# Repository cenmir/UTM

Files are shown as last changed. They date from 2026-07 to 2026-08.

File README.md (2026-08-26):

# Universal Testing Machine

Based on the work done by [Stefan from CNC kitchen](https://www.youtube.com/watch?v=uvn-J8CbtzM) and the students [Stephen Jose Mathew and Vijay Francis](https://hj.diva-portal.org/smash/get/diva2:1472019/FULLTEXT01.pdf) this is the continuation of that work. The machine is used at the Jönköping University - School of Engineering for teaching various mechanical engineering courses and the design, verification and validation of tensile testing equipment is in focus.

## Firmware

The firmware is is based on the HX711 amplifier, uses 10Hz polling rate and the TMC2160 driver on two MKS TMC2160_57 board, each driving a AMP57TH76-4280 Nema 23 stepper motor. The motors are geared down 20 times using EPL64/2 planetary gears. 

Rob Tillarts HX711 library is used to read raw values at 10Hz non-blocking (when data is available).

For drving the motors, one controll signal is sent to both drivers using the MobaTools library.

Additionally on each motor shaft end a magnet is attached and its rotational position contactlessly measured by a AS5600 magnetic encoder using Rob Tillats library. This is used to measure the rotational speed of the motors as well as getting the total amount of rotation.

## Software

The software is written in python using the PyQt6 framework for the GUI.

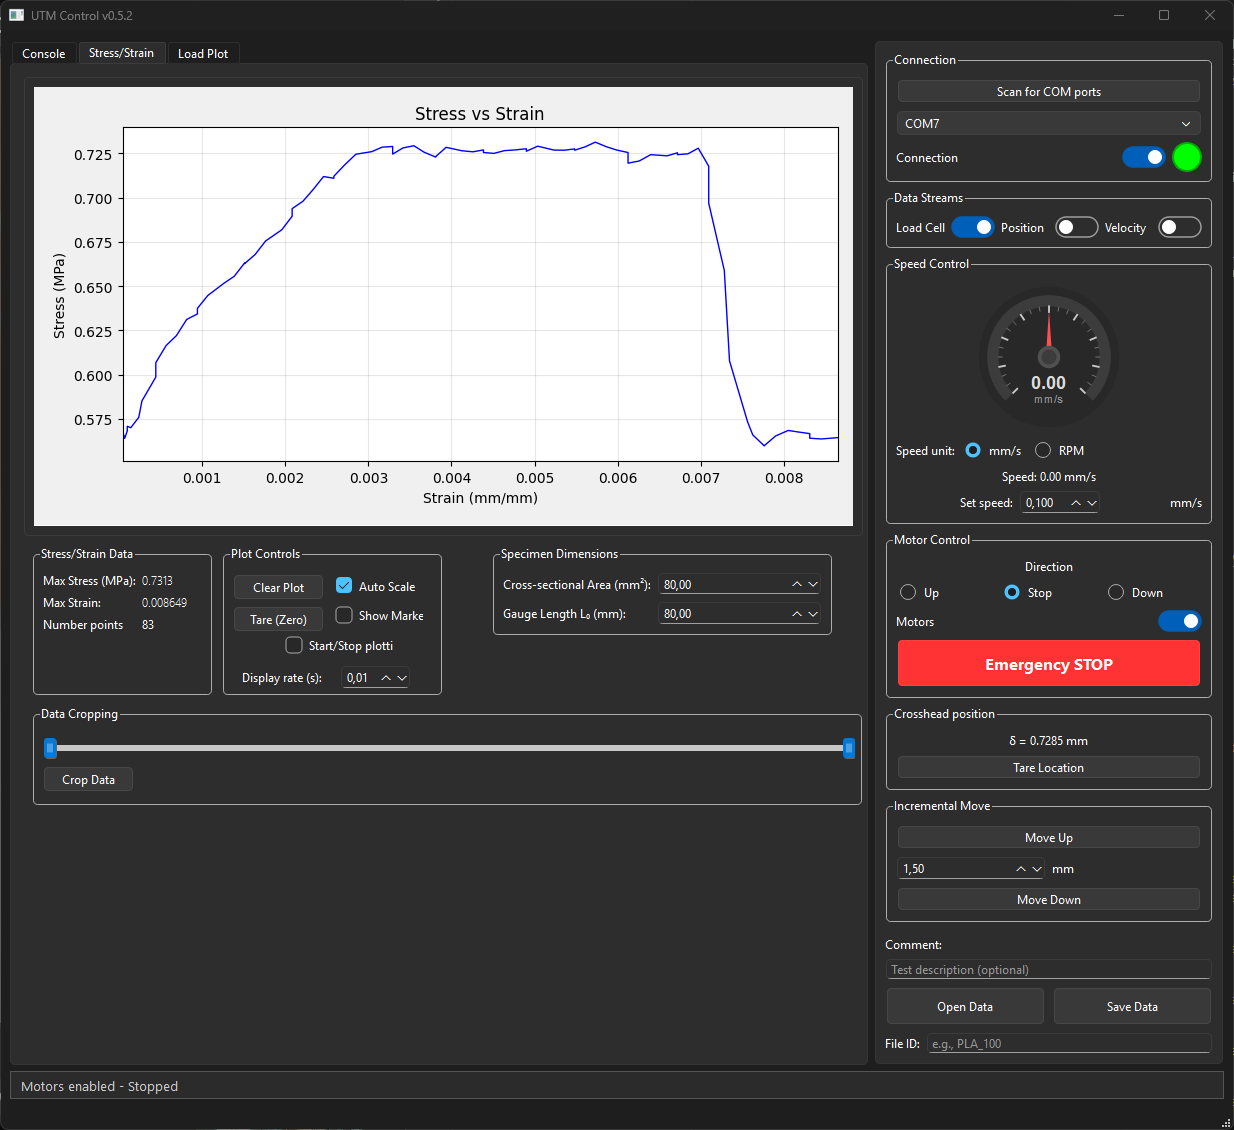
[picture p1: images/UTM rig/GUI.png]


## Hardware

### Mechanics BOM

| Qty | Component | Description |
|-----|---|---|
| 1 | [Aluminium Profile 80x80](https://www.alucon.se/product/aluminiumprofil-80x80-basic-t-spar-8-1-mm) | Frame extrusions |
| 2 | EPL-Q64 i20 | Planetary gearboxes (20:1 reduction) |
| 2 | Tr 22x5 TH22 | Trapezoidal lead screws (5mm pitch) |
| 4 | SKF-6005-2Z | Deep groove ball bearings |

### Electronics BOM

| Qty | Component | Description |
|-----|---|---|
| 2 | Nema 23 AMP57TH76-4280 | Stepper motors (1.85 Nm stall torque) |
| 2 | MKS TMC2160_57 | Stepper driver boards |
| 1 | ESP32 Lolin D32 | Microcontroller |
| 1 | HX711 | Load cell amplifier |
| 1 | Anyload 101BH-3t | Load cell (3 ton capacity) |
| 2 | AS5600 | Magnetic rotary encoders |

### Camera System (for DIC)

| Qty | Component | Specification |
|-----|---|---|
| 1 | Basler acA2440-35um | USB 3.0 camera |
| 1 | Azure-2514M | 25mm lens, 5MP, 2/3" sensor |
| - | LED lights | Specimen illumination |

## Digital Image Correlation

Two spray-painted markers on the specimen gauge are tracked in every camera frame. Their pixel
separation `L_px` against the frozen reference `Px₀` gives engineering strain directly on the
specimen, so the measurement carries no machine compliance and no grip slip.

### Hardware

Basler acA2440-35um over USB 3.0, 25 mm lens, LED illumination. The camera is mounted with the
specimen across the sensor, so every frame is rotated 90° before detection — the loading axis is
the *rotated* frame's Y.

### Software

`camera_manager.py` thresholds each frame, finds the two markers, and emits strain.
`utm_analysis.py` turns a saved CSV into E, σ_y, UTS, ε_f, toughness and the anchor. That module and
its siblings are deliberately **stdlib-only**, so results can be recomputed on any machine with no
camera stack installed.

---

# Getting started

```bash
git clone https://github.com/AdithyaSivakumar-3/UTM.git
cd UTM
python -m venv .venv && .venv\Scripts\activate      # Windows
pip install -r requirements.txt
python "Software/UTM_PyQt6/main.py"
```

Developed on **Python 3.14** and Windows. `requirements.txt` is grouped by what you want to do —
read the comments before installing everything.

**You do not need the rig to work on this.** `pypylon` is the only hardware-specific dependency;
skip it and every offline path still runs. Without a camera the app starts but cannot track.

## Where to look first

| File | What it is |
|---|---|
| `Software/UTM_PyQt6/docs/ROADMAP.md` | **Start here.** Living status of every feature: done, planned, blocked, and what needs rig time. |
| `Software/UTM_PyQt6/main.py` | The application. Control loop, live plots, CSV export, all UI. |
| `Software/UTM_PyQt6/camera_manager.py` | Camera, thresholding, marker detection, strain. |
| `Software/UTM_PyQt6/utm_analysis.py` | The canonical analyser. Every script and the app share it — do not re-implement it. |
| `Software/UTM_PyQt6/registry.json` | The specimen register: every test, with its computed properties. |
| `Software/UTM_PyQt6/dic_replay.py` | Replays a saved capture through the real detector and explains why tracking failed. |
| `documentation/` | Slide-deck and poster generators. Each rebuilds from data, never from typed-in numbers. |

## What is NOT in this repository

**The measured data itself.** `Software/UTM_PyQt6/Test data/` holds every test, in two folders
(`8.6.20 - Tensile test to Failure/` and `Smart Features - Advanced Test Modes/`). The folder
*structure* is committed, along with each run's `run.json`, generated report and photographs — but
the bulk is not:

| excluded | pattern | why |
|---|---|---|
| test CSVs | `*.csv` | the measurements themselves |
| capture stills | `**/frames*/`, `*.tif` | one specimen's stills run to 1.7 GB |
| capture video | `*.avi`, `*.mkv` | lossless by design |
| generated reports | `Software/UTM_PyQt6/reports/` | reproducible from the CSV |
| MOT session pack | `Validation docs/` | multi-GB videos |

The tree is ~54 GB in full. `registry.json` references the CSV paths, so analysis and deck scripts
will not find their inputs on a fresh clone — ask for the data folder separately if you need to
reproduce a result rather than write new code.

## Conventions worth knowing before you change anything

- **Engineering stress and strain** throughout. Force ÷ *original* area; ΔL/L₀. The CSV also carries
  a true-strain column, kept only so old files still parse.
- **Px₀ is frozen AFTER the preload**, so the strain axis starts at a seated specimen. It has
  exactly one owner — the Calibrate Px₀ button. Nothing else may move it.
- **Elastic modulus is the steepest straight run**, chosen per specimen, not a fixed strain window.
  `analyze()` also returns `E_fixed` so older numbers remain reproducible.
- **Fracture is detected on load collapse.** A DIC jump alone is not enough — it misfires on
  ductile material and on a lost marker.
- Force is tared at the preload, so an unloaded or fractured specimen reads *negative*.

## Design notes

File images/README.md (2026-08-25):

# images/

Figures used by the slide decks and the analysis scripts. These were loose in the repository root
until 2026-08-25; the names always said which test series they belonged to, so the folders just
make that visible.

| folder | what is in it |
|---|---|
| `V4/` | 8.6.19 / 8.6.3 staircase and linearity series |
| `V5/` | 8.6.20 V5 tensile-to-failure, and the V5a/b/c comparison set |
| `V6/` | V6 quintet — ductility, fracture patterns, offset factor, repeatability |
| `V6a/` | V6a 100 % infill series, including the V6a-vs-V5 overlays |
| `features/` | `feat_*` — proof figures for app features (auto-stop, strain rate, DIC halt …) |
| `rig/` | hardware and UI: enclosure CAD, DIC HUD and Settings screenshots, preload schedule |

Not to be confused with:

- **`graphics/`** — rig documentation referenced from `README.md` and `PROJECT_REQUIREMENTS.md`
  (GUI, schematic, dimensions). Different audience, so it stays where the docs point at it.
- **`documentation/*.png`** — figures generated by the deck builders that live beside them, and
  are rewritten on every build.

## If you move one of these

The scripts `chdir` to the repository root, so every reference is a path from the root such as
`"images/V6a/V6a_stress_strain.png"`. Grep for the filename before moving it — and note that
`pic_or_ph()` in the deck builders substitutes a PLACEHOLDER BOX for a missing image rather than
failing, so a broken path produces a deck that builds cleanly and is quietly wrong. After any
move, rebuild and check the picture count is unchanged:

```
python documentation/scripts/generate_v6a_slides.py
python -c "from pptx import Presentation; p=Presentation('documentation/decks/V6a_8_6_20_slides.pptx'); \
print(sum(1 for s in p.slides for sh in s.shapes if sh.shape_type==13), 'pictures')"
```

At the time of the move that was **90 pictures across 125 slides**.

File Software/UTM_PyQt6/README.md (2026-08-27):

# Software/UTM_PyQt6/

The UTM DIC application. `python main.py` from **this** directory starts it.

## Why the modules are flat

The 15 `.py` files beside `main.py` are the application. They import each other by bare module
name — `from camera_manager import CameraManager` — so they have to sit together on the path.
That is why they were left loose when everything else was filed away in 2026-08-25: putting them
in a subfolder would mean turning the app into a package and rewriting every import, which is a
different job with a different risk.

| module | role |
|---|---|
| `main.py` | the window, the control loop, the CSV writer |
| `camera_manager.py` | Basler capture, blob detection, DIC strain |
| `serial_manager.py` | the link to the rig firmware |
| `control_policies.py` | closed-loop test modes (strain rate, cyclic, staircase, …) |
| `utm_analysis.py` | the shared analyser: E, σ_y, UTS, ε_f, force anchor, fracture detection |
| `utm_registry.py` · `utm_report.py` | the test registry and the one-click per-test report |
| `utm_recipes.py` | saved settings profiles (`recipes/`) — Default, TPU |
| `utm_capture.py` · `utm_capdlg.py` | frame/video capture and its setup dialog |
| `utm_camdlg.py` · `utm_autocal.py` | DIC camera setup and auto-calibration |
| `utm_dic.py` · `utm_wizard.py` | DIC health readout and the guided wizard |
| `utm_postproc.py` · `utm_postdlg.py` | DIC post-processing: strain from a RECORDED video, and its tab |
| `theme.py` · `widgets.py` | look and custom controls |

## Folders

| folder | what |
|---|---|
| `tools/` | diagnostic and build scripts — ROI picker, blob checker, DIC replay, exe build |
| `tests script/` | camera and phase-8.6 test scripts |
| `docs/` | ROADMAP, TESTING_TODO, TEST_FAILURES, RECALIBRATE_ROI, COMMANDS |
| `ui/` | the Qt Designer `.ui` file, and `ui/help/` — the mode-help images |
| `recipes/` | saved settings profiles, seeded on first launch (Default, TPU) |
| `output/` | everything the app and its tools WRITE: `captures/`, `diagnostics/`, `setup_output/`, `full_frame_output/`, `test_images/`. Gitignored in one line |
| `Test data/` | every test CSV and its per-specimen folder — see below |

`CAPTURE_ROOT`, the `.ui` path, `ui/help` and `RECIPES_DIR` are all built from `__file__`, so they
follow the module — but they do NOT follow a folder that moves underneath them. A wrong one does
not raise; it points at a directory that is not there, and the symptom is a capture that never
appears or a help image that is blank. If you move any of these, check
`main.py` (`UI_FILE`, `CAPTURE_ROOT`, the `ui/help` lookup) and `utm_recipes.RECIPES_DIR`.

## Running anything in `tools/` or `tests script/`

From **this** directory, not from inside the subfolder:

```
cd Software/UTM_PyQt6
python tools/dic_replay.py
```

Their data and output paths are relative to this directory, and the ones that import app modules
carry a two-line header putting the parent on `sys.path`.

## DIC post-processing (the fourth tab)

Measures strain from a **recorded video** — ours, or a specimen filmed on the MOT XT-205 video
extensometer — so the two instruments can be compared on the same footing.

Load a video, place two tracking boxes on the speckle (or press Auto-detect for sprayed dots),
press Run. The strain-vs-time plot builds on the right as it goes.

**The strain maths is not re-implemented.** `utm_postproc` calls `utm_dic.dic_strain()`, and so
does the live camera path in `camera_manager.calculate_dic_strain()`. Strain is a pixel ratio —
`(L − L₀)/L₀` — with no gauge, calibration or unit in it, so a pull and the same pull replayed
from its recording must not be able to disagree.

Two things it gets right that are easy to get wrong:

- **Tracking is against the REFERENCE patch, not the previous frame.** Frame-to-frame tracking
  accumulates drift, and over 1682 frames a fraction of a pixel per frame exceeds the strain being
  measured. When correlation falls below the floor it re-seeds and FLAGS that frame rather than
  silently accumulating error.
- **Frame rate is measured, not believed.** Every video this rig has produced declares 35 fps in
  its container; S26 and S35 actually ran at 19.93 and S37 at 33.55. On load the tab reads the
  true rate from the capture folder's `frames/index.csv` (or `run.json`) and says where it got it.
  Videos from another camera have no sidecar, and the tab says so instead of assuming.

**Comparing several videos.** Add any number; each keeps its own extensometer, frame rate, box
size and tracking method, because two videos never have their markers in the same place and an
extensometer recording shares neither the frame rate nor the scale of ours. `Run all pending`
measures them one after another and every completed run stays on the plot with its own colour and
legend label. That is how an extensometer recording is put beside one of ours on the same axes,
measured with the same pixel-to-strain rule.

**Tracking method** is selectable, and the choice matters when comparing:

| mode | what it does | when |
|---|---|---|
| intensity-weighted centroid | contour selects the marker, intensity weights the centre | default — most precise |
| binary centroid | exactly what `camera_manager` does | comparing against a live run: removes the estimator as a variable |
| correlation | matches the pattern, no marker needed | speckle; chosen automatically when no marker is found |

Measured on S25/S26 over a matched strain window: intensity-weighted 15–17 µε, binary ~25 µε,
live rig 28 µε. Note the box size dominates all of it — a 24 px half-box on a 60 px dot gives
313 µε, because it sees only flat interior. Auto-detect and snapping now size the box to the marker.

Validated against S26: post-processing its `video.avi` reproduces that run's own live DIC to
**273 µε RMS over a 5.6 % strain range** (~0.5 % of reading), with L₀ agreeing to 0.005 %.

## Test data

Everything lives under **`Test data/`**, in two folders:

| folder | what | registry rows |
|---|---|---|
| `Test data/8.6.20 - Tensile test to Failure/` | the tensile-to-fracture campaign — one folder per specimen (`Specimen_S<n>_…`), each holding the CSV, its generated report/plots, and the frame-capture folder if the run recorded one | 27 |
| `Test data/Smart Features - Advanced Test Modes/` | the closed-loop protocol runs (cyclic, staircase, relaxation, creep) plus the older `8.6.3/` set | 7 |

They were gathered under one parent in the 2026-08 reorganisation; before that they sat loose in
this directory. **`registry.json` records every test by path**, and the deck builders in
`documentation/` read those same paths, so a move here invalidates both. Both were repointed at
the time, and the check is one line:

Run it **from the repository root**, not from this directory — the paths in `registry.json` are
stored relative to the root, so from here every one of them looks missing:

```
python -c "import json,os; r=json.load(open('Software/UTM_PyQt6/registry.json')); print(sum(1 for x in r if not os.path.isfile(x['csv'])),'unresolved of',len(r))"
```

That must print `0 unresolved`. If it does not, repoint by searching for each CSV's **basename**
rather than assuming where the folder went — specimen folders get renamed too (S37's gained a
`_Video15` suffix after its run, which broke its row and a hard-coded path in the deck scripts).

**The CSVs themselves are gitignored** (`*.csv`), as are the capture folders (`**/frames*/`,
`*.avi`, `*.mkv`, `*.tif`) — one specimen's stills run to 1.7 GB, and the tree as a whole is 54 GB.
What IS committed per specimen is the small stuff: `run.json`, the generated report PDF/PNGs, and
photographs. So the folder structure is in git while the bulk data stays local.

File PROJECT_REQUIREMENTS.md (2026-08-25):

# Project Requirements

This document outlines the hardware and software requirements for the Python-based Universal Testing Machine (UTM) application.

## Hardware

*   **Universal Testing Machine (UTM):** The existing custom-built machine with:
    *   2x Nema 23 stepper motors (AMP57TH76-4280) (1.85 Nm stall torque)
    *   2x MKS TMC2160 Nema23 driver board2
    *   1x HX711 load cell amplifier
    *   1x Anyload 101BH-3t load cell (3 ton capacity)
    *   2x AS5600 magnetic encoders
    *   1x ESP32 LolinD32 Board
    *   [Aluminium extrusions](https://www.alucon.se/product/aluminiumprofil-80x80-basic-t-spar-8-1-mm)
    *   2x EPL-Q64 i20
    *   2x Tr 22x5  TH22 Trapezoidal lead screws
    *   4x SKF-6005-2z Deep groove ball bearings
*   **Camera:**
    *   **Model:** Basler acA2440-35um
    *   **Interface:** USB 3.0
*   **Lens:**
    *   **Model:** Azure-2514M
    *   **Focal Length:** 25mm
    *   **Max Resolution:** 5MP
    *   **Sensor Format:** 2/3"
*   **Lighting:** LED lights for illuminating the test specimen.

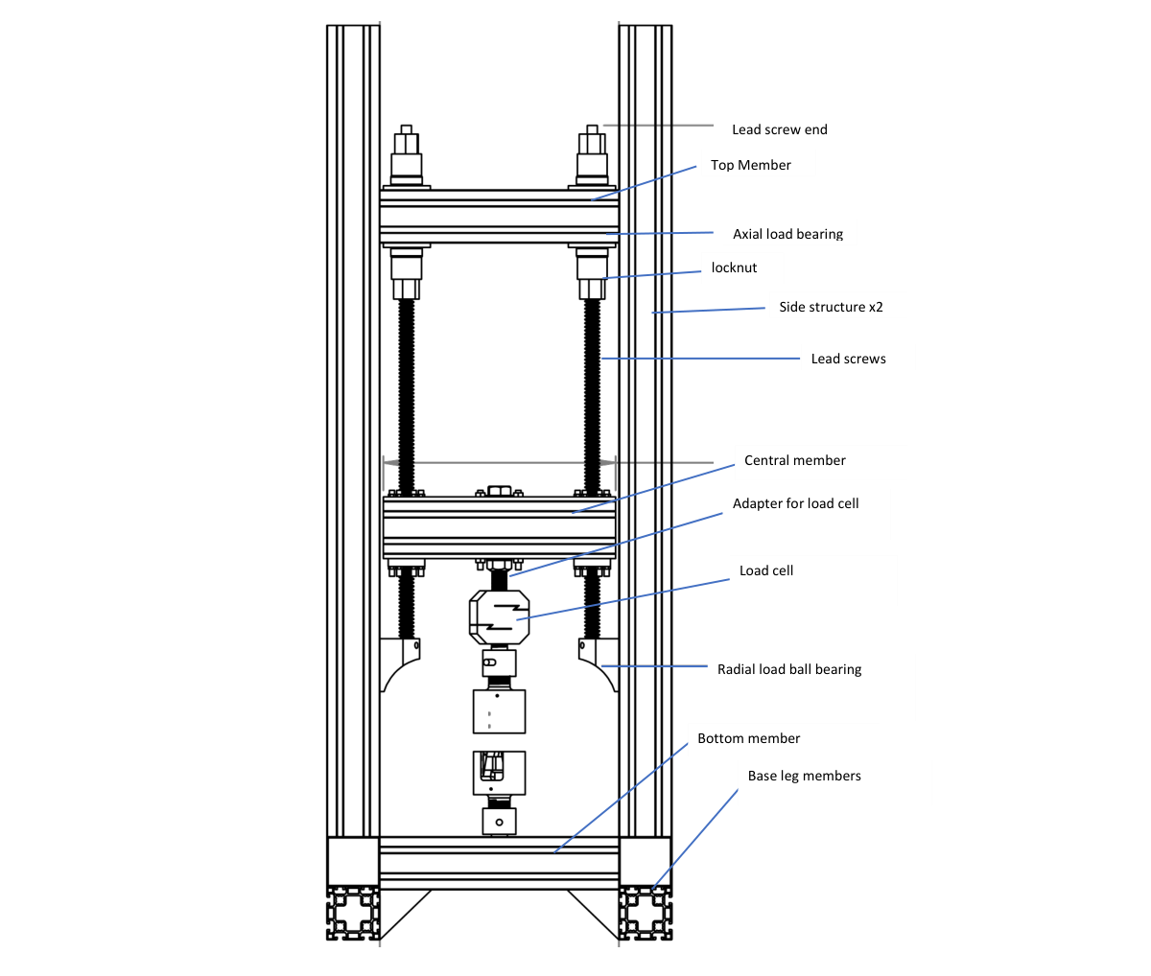
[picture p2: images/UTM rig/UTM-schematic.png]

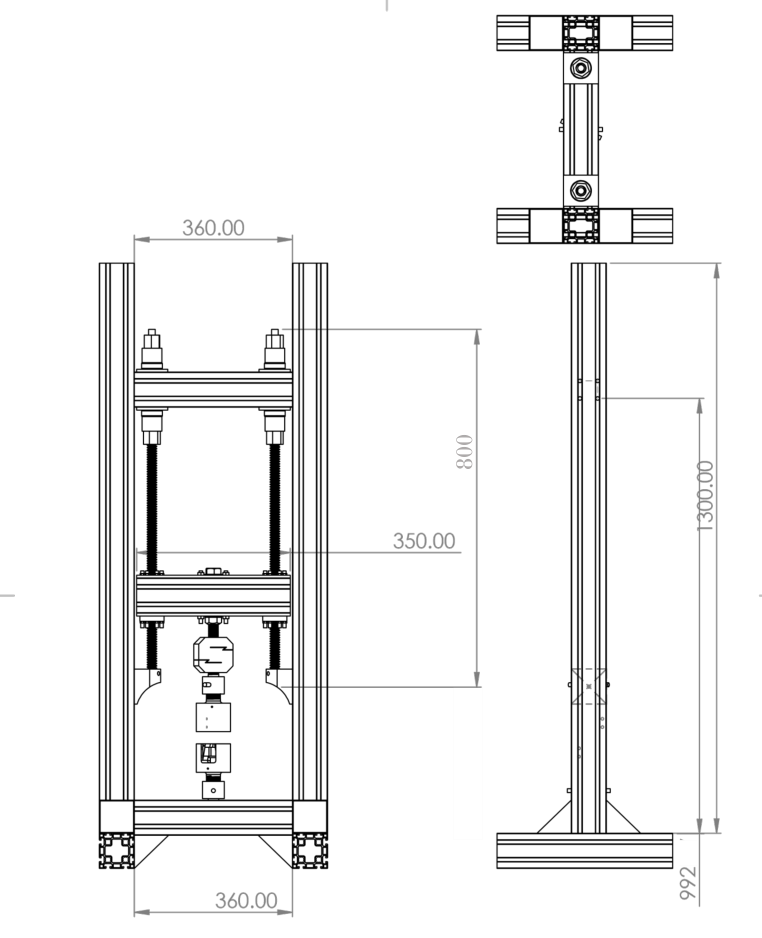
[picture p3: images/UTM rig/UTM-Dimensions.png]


## Software

### Core Libraries

*   **GUI Framework:** PyQt6
*   **Serial Communication:** `pyserial` for communicating with the Arduino microcontroller.
*   **Camera Integration:** A Python wrapper for the Basler Pylon SDK will be needed. The `pypylon` library is the standard for this.
*   **Numerical Computing:** `numpy` for handling numerical data and calculations.
*   **Plotting:** `pyqtgraph` or `matplotlib` for real-time data plotting within the PyQt6 application. `pyqtgraph` is generally recommended for high-performance real-time plotting in PyQt.
*   **Data Storage:** `pandas` and `h5py` (for HDF5) or a similar library for saving data.

### Digital Image Correlation (DIC)

*   **1D Two-Point Tracking:** The primary goal for DIC is to track two points on the specimen to measure strain.
*   **Image Processing:** `OpenCV-Python` (`opencv-python`) will be used for image manipulation, feature detection, and tracking.
*   **Algorithm:**
    1.  The user will select two points of interest (e.g., by clicking on the camera feed).
    2.  A feature detection algorithm (e.g., Shi-Tomasi corner detection or a simple blob detector) will be used to identify features within a small region of interest (ROI) around the selected points.
    3.  An optical flow algorithm (e.g., Lucas-Kanade) will be used to track these features from frame to frame.
    4.  The distance between the tracked points will be calculated in each frame to determine the elongation and, subsequently, the strain.

## Installation of Dependencies

The following commands will be needed to install the required Python packages:

```bash
pip install PyQt6
pip install pyserial
pip install numpy
pip install pyqtgraph
pip install pandas
pip install h5py
pip install opencv-python
pip install pypylon
```

**Note on `pypylon`:** The `pypylon` library requires the Basler Pylon SDK to be installed on the system. The user has indicated that the Basler Pylon 25.11.0 drivers are already installed.

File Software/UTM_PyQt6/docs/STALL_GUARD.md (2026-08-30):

# The velocity stall guard

**Status: ENABLED by default since 2026-08-30.** Operator switch in
**Motor Control ▸ Stall guard (velocity)**.

> **2026-08-30 — turned back on for the student campaign, by the project owner's decision.**
> It was switched off on 2026-08-28 for the reasons set out below, which still stand: this
> guard fires on healthy motion, and the fault it was written for was fixed mechanically.
> The judgement that reversed it is about who is at the rig. With ~40 groups running pulls
> largely unattended over seven weeks, a guard that occasionally stops a good move is the
> cheaper failure than one that is absent when a genuine bind happens.
>
> If it cries wolf during the campaign, reach for the **grace period** (`_start_movement_grace_period`,
> which covers the acceleration ramp) before reaching for the default. A student who is told
> to untick a safety box will leave it unticked.

This is the guard that prints:

```
⚠ WARNING: MOTOR STALL DETECTED!
⚠ Motors stopped for safety!
Motors DISABLED (stopped)
```

It is **not** the 0.05 mm / 6 s position guard described in `ROADMAP.md`. There are two
independent stall detectors and only this one is switchable.

| | velocity guard (this file) | position guard |
|---|---|---|
| where | `main.py` `_handle_motor_stall`, in the velocity handler | `_policy_step` / auto-stop path |
| test | motor RPM below a fixed floor | crosshead advance over a time window |
| scales with commanded speed | **no** | yes (`_stall_threshold_mm`) |
| switchable | **yes, default ON** | no |

---

## What it does

Fires when **all** of these hold:

1. `stall_detection_enabled` — **on** unless the operator unticks the box
2. Motors enabled
3. Direction is not Stop
4. Past the 1-second movement-start grace period
5. Not in a preload
6. **Both** instantaneous and averaged RPM below **0.5**, for **3 consecutive** readings

Then it sends `EStop`, disables the motors and resets direction to Stop.

---

## Why it was written, and why that reason is gone

| Date | Event |
|---|---|
| **2026-06-22** | `a4573d8` adds the guard. The rig is stalling near 2.6 kN. |
| 2026-07-28 | S15 stalls at 2.6 kN. **S16 fractures at 3792 N the same day**, +46 % on the same rig at the same speed. |
| **2026-08-12** | `9061daf` — the root cause is found. |

The "torque ceiling" was never a motor limit. **The load holders had worked loose, the
crossheads sat out of alignment, and the motor was spending its torque on binding instead of
on the specimen.** Re-tightened and lubricated, the rig pulls 3.5 kN with no stutter. The
commit puts it plainly: *"A fastener, not a purchase and not a code change."*

Eleven 100 %-infill specimens had already fractured at 3586–3826 N across three months —
straight through the supposed ceiling. The evidence was on disk before the fault was found.

**A mechanical fault was met with a software guard.** The guard did real work at the time:
S15 and T7 were caught by it and excluded from the results rather than silently averaged in.
But the fault it was compensating for has been repaired, and the guard outlived it.

---

## Why it misfires now

Two design faults, both visible in an ordinary jog:

**The averaged term lags the ramp at both ends.** From a real run:

```
<< Going up fast!
Velocity:   2.76 RPM (avg:   0.14 RPM)     <- avg still ~0 while the motor is turning
Velocity:   3.84 RPM (avg:   0.72 RPM)
...
Velocity: 453.99 RPM (avg: 451.83 RPM)
<< Stop and halt!
Velocity:   3.22 RPM (avg:  18.14 RPM)
Velocity:   0.00 RPM (avg:   9.53 RPM)     <- instantaneous 0 while avg is still high
```

Requiring *both* below 0.5 papers over this, but only by accident: any window where the ramp
is slow enough that both terms sit low — and the 1-second grace period has already expired —
reads as a stall on a perfectly healthy motor.

**The threshold does not scale with the commanded speed.** 0.5 RPM at the motor is
**0.00208 mm/s** at the crosshead, whatever speed was asked for:

| crosshead | motor | verdict |
|---|---|---|
| 0.100 mm/s | 24.0 RPM | ok |
| 0.010 mm/s | 2.4 RPM | ok |
| 0.005 mm/s | 1.2 RPM | ok |
| 0.002 mm/s | 0.48 RPM | **reads as a stall** |

A test slower than ~0.002 mm/s can never run with this guard on. The position guard already
solves this properly — `_stall_threshold_mm` scales the bar with commanded speed.

---

## If it is to come back

A stall is a **collapse from a commanded speed**, not an absolute floor. Any redesign should:

- **Compare against the commanded speed**, not a constant. Expected RPM is known:
  `rpm = mm_s / 5 * 20 * 60`. Flag when measured falls below some fraction of it.
- **Detect the drop**, not the level. A genuine stall is a sudden fall from a speed that was
  being held; a ramp is a rise from zero. The two are distinguishable by sign and by whether
  the motor has ever reached its commanded speed during this move.
- **Wait until the move has actually reached speed** before arming at all, instead of a flat
  1-second grace period that has no relationship to the ramp length (`setRampLen(100)`).
- **Cross-check the second encoder.** `D32_Firmware/src/main.cpp:35` pins `SENS_IDX 0`, so one
  sensor is trusted with no corroboration. Two encoders disagreeing is a far better stall
  signal than one encoder reading low, and it also catches the crosshead racking that caused
  the original fault. See `MECHANICAL_TODO.md` §2.

**Do not re-enable it by default until at least the first two are done.**

---

## The lesson worth keeping

The rig was carrying a hardware limit for three weeks and four causes were ranked on the T7
slide — three electrical, one mechanical. The mechanical one was ranked **last**. It was the
mechanical one.

When the machine misbehaves, check the machine before adding a guard to the software. A guard
that compensates for a mechanical fault hides the fault, and then outlives the repair.

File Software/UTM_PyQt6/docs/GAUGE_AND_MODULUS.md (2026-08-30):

# Gauge length, the modulus, and why the numbers moved

**Findings from 2026-08-30.** Four X-PLA specimens, 100 % infill, 80 mm² section, pulled to
fracture at 0.1 mm/s — one each at 80, 70, 60 and 50 mm gauge.

---

## 1. The gauge is 60 mm, not 80 mm

At 80 mm the marker dots land on the **fillets** of this dogbone, not inside the parallel
section. Confirmed on the fractured specimen: both dots sat at the shoulder transitions, and
the specimen broke *at* the lower one.

That is wrong twice over:

- Strain then averages over a region of **changing cross-section**, so it is not the gauge
  strain the stress is paired with.
- A fillet is a **stress concentration**. The material there strains more than the uniform
  gauge, so markers on it over-read strain and *understate* E.
- A specimen that breaks outside the gauge section is **not a valid tensile result** under
  ASTM D638 / ISO 527.

60 mm keeps both markers well inside the parallel section with clearance at each end, and has
a second benefit: L₀ drops to ~1270 px, which clears the framing check for a 30 mm pull
**without moving the camera**. At 80 mm the check failed by 38 px.

**Defaults changed 2026-08-30:** `main.py` runtime, the `.ui` spin box, and `utm_recipes`
all now start at 60 mm.

> ⚠ The gauge is a property of the SPECIMEN, not of the app. Measure the parallel section with
> calipers and put the real number in. 60 mm is the right default for the current dogbone; it
> is not a constant of nature.

---

## 2. What the four runs actually measured

| | 80 mm | 70 mm | 60 mm | 50 mm | spread |
|---|---|---|---|---|---|
| **UTS** | 41.02 | 40.78 | 40.46 | 40.22 MPa | **2.0 %** |
| **ε_f** | 2.89 | 2.85 | 2.81 | 3.20 % | 13 % |
| E *(adaptive rule)* | 3.240 | 4.705 | 3.503 | 2.756 GPa | **55 %** |
| σ_y *(adaptive)* | 37.65 | 32.89 | 33.94 | **1.28** MPa | broken |

**Strength is measured well.** Four specimens, UTS agreeing to 2.0 % — about 0.8 % CV on
printed dogbones. `UTS ≈ 40.6 MPa` for this X-PLA is defensible.

**The modulus was not.** 55 % spread on identical material. And it is *not* specimen scatter:
if it were, UTS would scatter too, and it does not. The fault is entirely in the small-strain
region where E is fitted.

Two causes, and only one of them is a defect:

- **PLA has no linear region.** E falls monotonically with strain in every run — 3.1 GPa at
  0.2-0.5 % down to 2.2 GPa at 0.7-1.3 % on the same specimen. "The modulus" is a property of
  the window you choose. That is real physics and worth teaching.
- **The adaptive `steepest straight run` rule picks a different window every run** — from
  0.01-0.26 % to 0.44-0.69 %. That turns genuine non-linearity into apparent randomness. The
  70 mm run's 4.705 GPa came from a window starting at 0.01 % strain: pure toe, physically
  meaningless.

---

## 3. ISO 527-1 fixes most of it

The standard removes the decision by prescribing the window, and removes the seating slack by
**correcting** for it rather than preloading it away:

```python
window = (eps >= 0.0005) & (eps <= 0.0025)        # ISO 527 strain window, 0.05-0.25 %
E_fit, intercept = np.polyfit(eps[window], sigma[window], 1)
eps_corrected = eps + intercept / E_fit            # slide the axis: the toe is the FIXTURE
offset_line = E_fit * (eps_corrected - 0.002)      # R_p0.2 is where the curve crosses it
```

Applied to the same four runs:

| | adaptive rule | **ISO 527-1** |
|---|---|---|
| E spread | 54.9 % | **28.7 %** |
| σ_y | one run gave 1.28 MPa | **all four sane, 14.3 % spread** |

```
gauge   E GPa    toe shift   Rp0.2    Rm      eps_break
80 mm   3.462    +0.047 %    35.41    40.93   2.93 %
70 mm   4.604    +0.152 %    33.14    40.78   3.00 %
60 mm   4.098    +0.109 %    30.74    40.20   2.92 %
50 mm   3.772    +0.153 %    31.39    38.96   3.35 %

E 3.984 GPa (28.7 %) · Rp0.2 32.67 MPa (14.3 %) · Rm 40.22 MPa (4.9 %)
```

**The toe correction is the part the analyser is missing**, and it is what fixed the broken
1.28 MPa yield. That value came from the offset line crossing almost immediately because the
strain zero sat slightly negative; sliding the axis so the fitted line passes through the
origin removes exactly that failure mode.

---

## 4. Preload: 100 N, not 300 N

**ISO 527 does not prescribe a preload force.** It handles seating slack by the toe correction
above — in evaluation, not in the fixture. So the preload only has to be *consistent* and
*small enough not to eat the fit window*.

Why 300 N is wrong for an ISO evaluation, on this specimen:

| preload | stress | strain already used up (E ≈ 3.5 GPa) | ISO window 0.05-0.25 % |
|---|---|---|---|
| 50 N | 0.63 MPa | 0.018 % | barely touched |
| **100 N** | **1.25 MPa** | **0.036 %** | **mostly intact** |
| 300 N | 3.75 MPa | **0.107 %** | **half the window gone** |

L₀ is frozen AFTER the preload, so whatever is already stretched into the specimen is excluded
by design. At 300 N that is 0.107 % strain — the recorded 0.05 % is really 0.157 %, and the
whole fit sits **above** the window the standard asks for.

**Use 100 N, the same every run.** Lower is better if it still seats the specimen; the toe
correction handles the rest.

The residual 29 % E spread points the same way: the **toe shift varied 3×** across these four
runs (+0.047 % to +0.153 %), and their L₀ was frozen at 0, 49, 101 and 105 N. Consistent
seating is the next lever.

---

## 5. What to quote, and with what confidence

| quantity | confidence | note |
|---|---|---|
| **UTS** | high | 2 % across four specimens. No fit window involved. |
| **ε_f** | good | 13 %. |
| **σ_y** | fair, with ISO | 14 % — and only after the toe correction. |
| **E** | quote WITH ITS WINDOW | 29 % even under ISO. Never compare two runs fitted differently. |

For the student campaign: UTS and ε_f are the numbers to build exercises on. E is a good
teaching topic precisely *because* it is not a single number — but it must be reported with
the strain window beside it, or forty groups will conclude the material varies when it is the
method that does.

---

## 6. What we cannot say

**Whether gauge length itself affects the result.** One specimen per gauge means gauge effect
and specimen scatter are perfectly confounded. E vs gauge correlates at r = +0.41 and E vs
preload at r = +0.21 — at n = 4 neither means anything.

**n ≥ 3 per gauge** would separate them. Given how tight UTS is, gauge length is unlikely to be
the driver.

---

## 7. Open

- [ ] Implement ISO 527-1 in `utm_analysis.py` — prescribed window + toe correction — reported
      **alongside** the existing `E` so historical numbers stay recoverable.
- [ ] Clamp any fit whose window starts below ~0.1 % strain. That is what produced 4.7 GPa.
- [ ] Standardise the preload at 100 N and check whether the toe shift tightens.
- [ ] The 80 mm specimen fractured **at a fillet**. If that recurs, the fillet radius is too
      tight and it is a specimen-design problem, not a test one.

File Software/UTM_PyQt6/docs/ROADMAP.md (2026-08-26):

# UTM DIC — Innovation & Automation Roadmap

Status of the "smart UTM" features (automated test modes, live DIC, one-click workflow, safety).
Living source of truth; the V6a deck's roadmap slides are generated to match this.

**Legend:** ✅ done + **rig-validated** · 🟢 built (offline/sim-validated) · 🟡 partial / in progress · ⬜ planned · 🔴 blocked by hardware

_Last updated: 2026-08-21 — MOT extensometer comparison analysed, the Black preset moved off Otsu
to a fixed threshold, two pair-plausibility guards added, and the motor "torque ceiling" resolved as
a misalignment; deck now pages 141-247 (107 slides). Earlier milestones: 2026-08-18 S13 + S27/S28 +
the E fit window + SF13; 2026-08-11 T6.5 + T9; 2026-07-29 full rig-test campaign._

---

## 1. Implemented & validated

### Shared foundations (offline modules, tracked in git)
| Feature | Module | Status | Evidence |
|---|---|---|---|
| Shared analysis library (E, σ_y, UTS, ε_f, toughness, anchor, fracture detector) | `utm_analysis.py` | ✅ | Reproduces V5/V6 deck numbers (UTS 46.2 / E 2.60 etc.) |
| Closed-loop control engine (Force/Strain-rate/Cyclic/Staircase/Relaxation/Creep policies + sim) | `control_policies.py`, `control_sim.py` | 🟢 | 9/9 sim checks pass |
| Recipes / settings (save + reload test setups, always-present Default) | `utm_recipes.py` | ✅ | Round-trip verified on the rig |
| Test registry (one queryable index of every test + anchor) | `utm_registry.py`, `registry.json` | ✅ | Seeded 8.6.20 tests; S16 added |
| One-click per-specimen report (PDF + PNGs) | `utm_report.py` | ✅ | Every KPI verified vs CSV (S16) |
| Live-DIC helpers (health + multi-marker geometry) | `utm_dic.py` | 🟢 | Self-tested (ν=0.35 recovered) |

### App features (in `main.py`, snapshot `a3b187f`) — all rig-validated
- **DIC health HUD** — OK/WARN/BAD badge (markers · tracking % · jitter) on both test tabs.
- **Prepare specimen** — one-button tare (position + force + DIC), clears consoles + stress-strain plot; DIC tares only at green 2/2.
- **Settings** — Load / Save… + always-present **Default** (auto-stop ON), infill label.
- **Generate report** — one button → PDF + PNGs.
- **Release load — TWO depths** (2026-08-13). The reading is tared at the preload, so tared 0 N and
  true 0 N are ~300 N apart on this rig and "release" means two different things:
  **Release to preload** stops at tared ~0 N (test load gone, preload STILL on — the specimen stays
  mounted and tensioned for the next run), **Release fully** drives on to −(tared-away) = true zero
  so the specimen can be unclamped. One shared loop and one shared safety net (rise cap · relative
  compression floor · timeout); only the target differs.
  **Two buttons, deliberately not a tickbox:** the depth decides how far a motor travels toward
  compression, so it must be named on the control being pressed rather than held in state set
  minutes earlier. Mid-release the pressed button becomes *Cancel release* and the other greys out,
  so there is never a second live motion button. Costs one 26 px row inside the control panel's own
  scroll area — the main page budget is untouched (+11 px headroom either way).
- **Fracture test** button — checklist → arm auto-stop → tension pull → auto-stop at fracture.
- **Auto-stop at fracture** — live load-collapse detector on a manual pull.
- **Strain-rate fracture test** — closed-loop constant *gauge* strain rate → fracture → auto-stop.
- **Safety net (3 layers):** load-collapse fracture detector · **stall guard** (crosshead frozen <0.05 mm/6 s under load — in BOTH the auto-stop path and the strain-rate loop) · **10 kN / 30 mm** force/travel backstop · **dead-DIC guard** (freeze speed at 0.2 s, halt at 1.0 s).
- **CSV richness** — `DIC_Blobs` health column + `# DIC Health` header + infill label.
- **SF12 — DIC auto-calibration + live parameter readout** (2026-08-14). The preset's exposure and
  threshold were chosen once by hand under one set of LEDs; when the lighting drifts they quietly
  stop being right and the first symptom is a ruined test. `utm_autocal.py` scores a frame's
  TRACKABILITY (pure NumPy/OpenCV, no camera or Qt, so it is testable): two blobs is a hard gate,
  then **contrast margin** dominates — how far the markers sit from the cut — because that predicts
  whether tracking SURVIVES a flicker, where the other terms only describe how comfortable it is
  now. Headroom (clipping), area-in-band and circularity make up the rest.
  `Settings ▸ Auto-calibrate DIC…` sweeps exposure × threshold, scores several frames per setting
  (a single frame can look excellent on noise alone), and **proposes** — a dialog with the
  before/after table; Cancel restores the camera exactly. Threshold picks the CENTRE of the widest
  working band, not the peak: a setting with room either side survives a drift, a peak on a cliff
  does not. Measured: the rig's fixed 150 finds **0 blobs** on a dim frame where auto picks 70 and
  succeeds. The sweep is relative to the current exposure, so a badly-wrong start can leave the
  optimum outside the range — a winner at either END is flagged, and re-running converges
  (9 → 25 → 50 ms against a true 60 ms, score 0.00 → 0.92).
  ⚠️ **Session-only** — the preset in `camera_manager.py` is untouched, so a restart returns to the
  hand-set values. Refuses to run mid-capture (would put mixed settings in one recording).
  **Two routes, `Settings ▸ DIC camera setup`:** *Auto-calibrate…* (the sweep) and *Set parameters
  manually…* — a dialog for exposure / threshold / Otsu / area gates / circularity with a **live
  trackability readout** that re-scores the current frame on every keystroke, so you can see whether
  a value tracks before committing. Exposure is pushed to the sensor as you drag it (the feed
  reacts), which is exactly why Cancel restores it. Typing numbers blind is how the preset came to
  be wrong in the first place. Kept as two ACTIONS rather than a Manual/Auto radio pair: a mode
  whose only effect is to open a dialog is not a mode, and a stale radio would claim a state the
  camera is not in.
  Live parameters now show in the **DIC Camera group titles** (`exp 50.0 ms · thr 150 · 35 fps ·
  419×2348 · mean 171`) — free real estate, since the info row is full and the page has ~11 px of
  vertical headroom. Otsu presets read `thr auto (Otsu)`, not a misleading `thr 0`.
- **SF11 — auto-metadata / capture↔CSV link** (2026-08-14). A run left three artefacts with nothing
  joining them: the CSV, the report, and a multi-gigabyte capture folder. Pressing Save now:
  writes `# Capture: <folder>` into the CSV header and `run.json` (csv path, File ID, geometry,
  recording window, app version) into the capture folder, so **either half finds the other**;
  appends the row to `registry.json` (default ON); optionally builds the report (default OFF).
  The capture is matched to the data by **time-window OVERLAP, not recency** — run two tests before
  saving and "most recent" silently attaches the wrong frames to the force data, and a mislabelled
  link is worse than none because it looks authoritative. `utm_analysis.read_meta` parses the new
  key (splitting on the FIRST colon only, or a Windows drive letter truncates the path).
  Registry auto-add self-skips on a non-destructive run — `analyze()` needs a fracture — and says so
  rather than raising. ⬜ Per-specimen FOLDERING is deliberately not included: silently redirecting
  where a file lands is riskier than the typing it saves.
- **GUI responsiveness** (2026-08-13) — the app was spending **~700 ms of every wall-clock second**
  on the single GUI thread, which is what the lag was. Measured, not guessed (`perf_probe.py`):
  one matplotlib redraw of these figures costs **22.5 ms** (14.2 ms of it is the datetime axis), and
  one camera frame costs **5.9 ms** on the GUI thread. Four fixes, none of which touch a measurement:
  - **Hidden tabs no longer redraw.** Only one plot tab is ever on screen, yet both canvases redrew
    every tick — half the plotting was invisible by construction. The dirty flag stays SET so the tab
    catches up when shown (`_on_plot_tab_changed`, deferred one event-loop turn because on the
    tab-changed signal the new page is not visible yet). On the Console tab, plotting cost is zero.
  - **Camera feed throttled to 12 fps.** Every frame is still GRABBED and MEASURED at 35 fps — only
    the picture is throttled. 35 back-to-back frames: **206 ms → 16 ms**.
  - **Centroids ship with the frame** (`frame_ready(ndarray, list)`). The GUI used to re-run
    `detect_blobs` on the frame it had just been handed — a second detection pass, a second
    `blobs_detected`/`error_occurred` per frame (**double-counting every dropout in the health HUD**),
    and a chance to pair markers with the wrong frame once the GUI fell behind. A correctness fix as
    much as a speed one. PyQt truncates args for the 1-arg slots in `camera_setup`/`check_blobs`.
  - **Repeat spam coalesced** — the per-frame `print` now fires on a CHANGE of marker count then at
    most 1 Hz; identical `[Camera Error]` lines collapse to one per second with a repeat count. The
    HUD still sees every frame, so tracking % stays exact. Display-rate default **0.01 s → 0.10 s**
    (it was polling at 100 Hz for data that arrives at 11 Hz).
  - **Net ≈ 700 → 285 ms/s.** ⬜ Remaining lever if it still lags: **blit the live traces** (~22 ms →
    ~2 ms), which needs stepped axis limits so the background cache is not invalidated every sample.
- **Calibrate Px₀ + frozen-reference overlay** (2026-08-12/13) — the DIC zero was previously only
  reachable through *Prepare test*, i.e. **after** preload, which silently discards everything
  already stretched into the specimen (~2500 µε at 300 N = 96× the noise floor). Now an explicit
  **Calibrate Px₀** button freezes the reference before preload, behind a mounted-specimen
  confirmation that turns into a warning above 25 N; *Prepare test* no longer overwrites a Px₀ that
  was captured at a lower load. The live feed then draws **both** marker pairs — frozen in cyan
  (dashed, larger ring, over a **near-black casing**) and live in green (solid) — plus a per-marker
  travel caliper and a `Px0 1665 → now 1725 px (+60)` caption on a filled plate.
  The casing is not decoration: the frozen ring straddles the EDGE of the speckle blob, so one
  stroke crosses near-black and near-white within a few pixels and no flat colour survives it. It
  must OPPOSE the mark — cyan needs a dark casing (a white one, which suited an earlier dark-blue
  trial, washed the travel arrows out against the bright specimen).
  Draw order matters as much as colour: **live first, frozen dashes on top**. Underneath a solid
  green line the frozen line showed only a hairline of colour, which averages to teal at the ~0.4
  display scale; on top, the dash gaps show green and both read fully saturated.
  ⚠️ Cyan is the operator's choice on RIG visibility, and it is the weakest pair against the live
  green on paper: OKLab ΔE×100 worst case across protan/deutan/tritan is **5.1**, vs dark blue 44.5
  · violet 33.9 · magenta 29.3 · royal blue 26.0. Acceptable ONLY because the overlay never relies
  on hue alone — dash pattern and ring **radius** both separate the pairs independently. The radius
  is load-bearing: at the instant of calibration the pairs are exactly concentric, so same-size rings
  would vanish into each other. Makes a bad tare — slack specimen, tare under load, a marker that jumped blobs — visible on
  the feed instead of only in the strain number. Two arrows growing outward = stretch; both pointing
  the same way = the whole field translated (rig slip / camera knock), which strain alone hides.
- **Dark / light theme** (2026-08-12) — **dark is the default**; `View ▸ Appearance` or Ctrl+Shift+D /
  Ctrl+Shift+L, remembered across restarts. `theme.py` holds both palettes. A theme is not just a Qt
  stylesheet: the two embedded matplotlib canvases are plain artists that know nothing about Qt and
  must be restyled explicitly (facecolour, spines, ticks, labels, grid, hover box, crosshairs, traces)
  and redrawn, and the custom-painted `RangeSlider` groove needs its own setter because QSS cannot
  reach a `paintEvent`. LIGHT is deliberately an EMPTY stylesheet — the app's original look — so
  switching back is a true revert rather than a second theme to keep in sync.
  ⚠️ **Not given an SF number, on purpose:** the SF registry tracks TEST capability, not chrome. The
  admission test ("can the operator invoke it?") is necessary but not sufficient — it also has to
  change what the rig can measure or how safely it runs.

### Rig-validation highlights (2026-07-28/29)
- **S16** — first successful 100 % infill fracture: UTS 47.4 MPa (anchor-corrected), auto-stop caught it, stall guard correctly silent through the ductile draw.
- **#6.1** — dead-DIC guard fires on marker loss; staged freeze/halt tuned (T2/T3: overshoot 518 → 175 N).
- **#6.2** — strain-rate to fracture on a 50 % specimen: **held 0.00051 /s vs 0.0005 target** while the crosshead **auto-adapted 0.10 → 0.05 mm/s** (fast in stiff elastic, slow in necking) = true constant-strain-rate control; fractured (UTS 17.3 MPa nominal), auto-stopped on load collapse.
- **3 rig facts resolved:** Stop holds position · direct reversal auto-decels ~1 s · travel cap 30 mm.

---

## 2. Partial / in progress
- 🟡 **Closed-loop test modes (Phase B):** strain-rate ✅ done & validated. The other four — **cyclic, staircase, relaxation, creep** — are **🟢 WIRED** ("Advanced test modes" segment: enable checkbox → Test-type dropdown + per-mode settings + **?** help diagram + Start test), sharing the same `_policy_step` loop + safety net. `_policy_step` drives **tension / compression / hold** with **phase-aware guards** (stall guard silent during an intentional hold; dead-DIC guard only for DIC-steered modes) + adaptive timeout.
  - ✅ **Rig-validated 2026-08-08 (scrap #1, 100 % infill):** **creep** (held ~400 N, 80 s) · **relaxation** (ε 0.010 → force decayed 2145→2040 N at fixed strain) · **staircase Linear vs Smooth** (3 levels, 20 s dwells; Smooth cut arrival overshoot **45/47/53 N → 6/5/8 N**). Stall guard silent through all 8 intentional holds. Two overshoot fixes landed (creep + staircase now taper the last 25 % of each approach). See `TESTING_TODO.md` §7.
  - ✅ **Session 3 — cyclic DONE** (T5 Triangle, T6 Sine → T6.3 after the sine/reversal fixes). All six modes are now rig-validated; only the **deck slides** remain (§3a).
- 🟡 **Multi-marker Poisson / true Cauchy:** math ready in `utm_dic.py`; needs a 4-marker specimen preset + camera wiring. Also limited by the current mini-dogbone (narrow gauge, sub-pixel transverse change) → see §4.

---

## 3. Remaining / planned  (checklist)

### 3a. Near-term deliverables  ⭐ next up

> ## ▶ NEXT UP — everything above the line was CLEARED on 2026-08-12
>
> **✅ Cleared 2026-08-12** (all verified against the raw CSVs, then re-checked in the rendered files):
> the S22 cycle count (15 → **16**, and now **computed** by `sf9_data.n_cyc_s22` from the load extrema
> so it cannot drift again) · "one rig run" → **two** · the 0.9 % cross-protocol caveat · the stale
> **13/17** KPI tiles (now derived from `N_DONE`) · deck slide 169 rebuilt **8 → 16 cards** ·
> the **infill-label reset** (root-caused and fixed) · the **`main.py` snapshot commit**.
>
> **⬜ Rig time — these need a specimen and the machine; nothing else blocks them:**
> 1. **T6.6, the damage curve.** Fresh 50 % specimen, 400→1100 N, 12 cycles, sine, 0.100 mm/s, ONE
>    uninterrupted run, baseline E on cycle 2. ~40 min. The only route to D = 1 − Eᵢ/E₀.
> 2. **✅ Black-specimen DIC check — CLEARED 2026-08-18 by S13.** Deck **p225–231**. The Black
>    preset had never run on a real specimen; its ROI was still the pre-recalibration crop, too
>    small in both directions to hold a 1665 px marker pair, so a marker was cropped off the sensor
>    before detection ran (`f122259`). With that fixed: markers found on **99.9 %** of frames, noise
>    **11.9 µε against 14.3 µε** for the white pair (17 % QUIETER, common 10 s window), and every
>    mechanical property closer to the white mean than the two white runs are to each other
>    (UTS 0.7 % vs 2.2 %, E 4.5 % vs 17.1 %, ε_f 3.8 % vs 31.6 %). Black is cleared for use.
>    S12 was the first attempt and did not come out; its folder is kept for the record.
>    ▸ n = 1. A second black specimen would turn this into a repeat, but nothing is blocked on it.
> 3. **Live Px₀ overlay — VALIDATE ON THE RIG.** Built and render-checked 2026-08-13 (`db7ad37`)
>    against a synthetic frame only. On a real specimen, confirm: the frozen cyan pair lands on the
>    markers and does not drift; the green pair separates from it as load rises; the caption Δ agrees
>    with the strain readout (Δpx/Px₀ = ε); and the calipers grow OUTWARD rather than both one way.
>    Blocked behind a lighting problem the operator is working on.
>
> 4. **✅ Capture feature — VALIDATED ON THE RIG 2026-08-17** (built 2026-08-13,
>    `18551c4`…`670d630`). Three pulls to fracture with PNG + AVI on: S24 (VC1), S25 (VC2), S26
>    (VC3). S25/S26 gave 3 127 stills and 3 × 3 127 AVI frames across raw/boost/speckle, **0
>    dropped**, 19.9 fps, all four sinks in step, `run.json` → CSV correct, **100 % DIC coverage**,
>    and both videos open ≈0.6 s before the crosshead moves and run 4.6 s past fracture. Replaying
>    every frame through the app's own detector found 2 markers on 99.8 / 99.9 %. Deck p217–222.
>    S24 logged only 27 % DIC coverage — frames all present and distinct, so the loss was in the
>    load↔DIC matching step; it has not recurred and is not currently reproducible.
>
> 5. **✅ S27 / S28 ANALYSED 2026-08-18 — the 50 % infill video pair.** Deck **p232–236**, plus
>    **p237–242** for the deviation and the 50-vs-100 comparison. The pair is the tightest on
>    record: **UTS 19.87 vs 19.91 MPa (0.2 % apart)**, ε_f 4.0/4.2 %, E 1.22/1.26 GPa, both with
>    full capture integrity. **The infill knock-down is confirmed as an infill effect and not an
>    instrument one:** 50 % needs k ≈ 2.4 against literature while 100 % lands at k ≈ 1.05–1.24, on
>    the same rig, the same DIC and now the same E rule. This closes the MOT extensometer
>    prerequisite.
>
> 6. **⬜ WHY DID DIC DELIVERY SLOW? — NARROWED 2026-08-21, still open.** Measured across three
>    runs (filtering `L_px > 100 AND DIC_Time_s > 0`; the uncovered rows carry 0.000, not NaN, and
>    a first pass that missed that produced "7323 s lost in a 95 s run"):
>
>    | run | mode | tracked 2/2 | DISTINCT readings reaching a load row | median gap | gaps > 250 ms | coverage |
>    |---|---|---|---|---|---|---|
>    | S26 | White | 99.9 % | **11.1 Hz** | 100 ms | 0 | **99.9 %** |
>    | S29 | Black | 100 % | 8.9 Hz | 101 ms | 33 (10 % of run) | 78.8 % |
>    | S13 | Black | 99.9 % | **5.3 Hz** | 147 ms | 175 (**51 % of run**) | 47.4 % |
>
>    ▸ **Coverage tracks delivery rate almost exactly**, so the 100 ms matching window is NOT the
>    fault — it is doing its job on readings that never arrive. S26 sits at the ceiling the load
>    sampling allows (~11.4 Hz); the other two are genuinely below it.
>    ▸ **The loss is DOWNSTREAM OF DETECTION.** Camera 19.9 fps with 0 dropped, detector finds two
>    markers on ~100 % of frames, and S29's own `# DIC Loop` header line reads TOTAL 50.2 ms
>    (19.9 Hz) with detect at 1.0 ms. Frames are found and strain is computed; the readings do not
>    reach the consumer.
>    ▸ **Both degraded runs are BLACK-mode, the healthy one is White.** That is the strongest lead
>    and it is only n = 3 — worth confirming on the next Black run before believing it.
>    ▸ Do NOT widen the 100 ms window: it would pair load samples with staler strain and hide this.

> **✅ MOT VIDEO-EXTENSOMETER COMPARISON — ANALYSED 2026-08-20. Deck p245–247.**
>    XT-205, gauge 80.0033 mm, 20 Hz, strain only, stops at 0.401 %. MOT matched our 300 N preload
>    and 0.10 mm/s, and their gauge equals ours, so the strain zero and the rate needed no correction.
>    ▸ **THE RESULT: our DIC is more CONSISTENT.** Residual scatter over the same 0.05–0.35 %
>    interval — RMS **23.5 / 23.6 µε** against the XT-205's **44.9**. But quote it carefully: the
>    XT-205 holds the QUIETEST baseline of the three (median |r| 12 µε vs our 13 and 17) and loses
>    on RMS only through a few large excursions (p95 116 µε vs our 45). Ours is not finer, it is
>    more consistent. Our two runs agree with each other to 0.4 %.
>    ▸ **The rate ratio does NOT test our scale**, and the deck says so: MOT reads 2.21× faster
>    (7.42 vs 2.67/4.06 ×10⁻⁴/s), which is the expected direction because only **19–29 % of our
>    crosshead motion reaches the gauge** and that fraction belongs to the MACHINE.
>    ▸ **⬜ STILL OPEN — ask MOT for their LOAD or CROSSHEAD-DISPLACEMENT channel.** With either,
>    strain can be compared at matched force or matched displacement, which cancels the compliance
>    term and turns this into a real scale check. Cheap to ask, and the only thing left.
>    ▸ Side finding, and the clearest evidence yet on the seating question: **our local strain rate
>    CLIMBS through the ramp while theirs is flat from the moment it engages.** That is why S25 and
>    S26 differ by 52 % on early-strain rate but agree to 1.4 % force-matched. The residual
>    low-strain compliance is the RIG, not PLA non-linearity.
>
> **⬜ NEW CAMPAIGN — PETG and TPU against PLA.** IN PROGRESS.
>    ▸ **REDO S29 FIRST — it produced NO valid properties.** Two tracking faults, both now fixed:
>    attempt 1 tracked at 17 % (Otsu below PETG's window → fixed threshold 149), attempt 2 tracked
>    at 100 % and was still lost when ONE frame in 1222 read the mount holder as a marker and the
>    bogus strain jump tripped the fracture detector AT PEAK LOAD, auto-stopping an intact
>    specimen at 2931 N / 36.6 MPa. Its registry row has the fracture-derived fields nulled.
>    Black tape on the mount edge is still worth adding as belt-and-braces. Everything on record so far is PLA, so every claim the rig
>    makes is single-material; a second and third polymer is what turns "the rig measures PLA" into
>    "the rig measures polymers".
>    ▸ **The question is whether the TREND comes out right**, not just whether the numbers do.
>    Expected ordering, from the datasheets: **PLA stiffest and most brittle** (E ~2.9 GPa, ε_f
>    ~8 %), **PETG less stiff but far more ductile** (E ~1.5–2.1 GPa, ε_f tens of %), **TPU a
>    different class entirely** — elastomeric, E in the low MPa, strain to break in the hundreds of
>    %. If the rig reproduces that ordering it is measuring material, not itself.
>    ▸ **PETG gets a like-for-like reference check**, the same treatment PLA got against the
>    add:north E-PLA TDS: find the TDS for the actual filament used, and compare E / σ_y / UTS /
>    ε_f the same way, with the same infill knock-down caveat. **Log the exact brand, spool and
>    print settings at test time** — the PLA reference only worked because the filament was known.
>    ▸ **Two things to decide before TPU, not after:** (a) ε_f in the hundreds of % will run past the
>    30 mm travel cap and probably out of the DIC field — expect the markers to leave the ROI, so
>    treat TPU as a crosshead-strain test with DIC as a bonus, or shorten the gauge; (b) the
>    load-collapse fracture detector is tuned for a brittle drop — a TPU that draws without ever
>    collapsing may never trigger it, exactly like the ductile 100 % PLA case that made
>    load-collapse the ONLY detector. Check the guard before spending a specimen.
>    ▸ Run them on the post-realignment rig (above), same 0.10 mm/s, same preload discipline, so
>    material is the only variable that moves.
>
> **⬜ Software, in the order I would take it:**
> 7. **✅ SF13 — guided wizard. BUILT 2026-08-18.** `Software/UTM_PyQt6/utm_wizard.py` +
>    View ▸ Guided wizard (Ctrl+Shift+G). **Optional and OFF by default**, at the operator's
>    request: it encodes a real procedure but somebody who knows it does not need a panel reciting
>    it, and a checklist that cannot be dismissed is just a wider warning.
>    It is a VIEW — `steps()` is a pure read of flags that already existed, so it cannot disagree
>    with the app, and an AST check in the suite proves it reaches no control path at all. The one
>    new piece of state is `_prepared_t`, stamped by Prepare test, which was the only step with no
>    durable trace. Nine steps; the Px₀ row is the point of it — under the after-preload convention
>    a Px₀ frozen unloaded shows a warning instead of a tick.
>    Extended the same day at the operator's request: the **data-streams** step (load cell +
>    position gate the run; velocity is reported but never blocks), **"Choose specimen mode"** as an
>    instruction rather than a value, each optional step saying **WHERE** it lives
>    (Settings ▸ Capture settings), and the run step naming all three routes — fracture test, a
>    manual pull, or an advanced mode. Twelve rows, nine of them blocking.
>    ▸ **✅ RIG-VALIDATED 2026-08-21** — the operator confirms the panel works on the machine.
>    ▸ **Auto-calibrate added as an OPTIONAL step 2026-08-22**, between choosing the specimen
>    mode and applying the preload — it needs the camera live and the mode chosen, and nothing
>    after it depends on it. INFO, so it can never gate a test. It reads the live exposure and
>    threshold and says they were **carried over from the last run** until it has been used,
>    because a value measured on a different specimen looks exactly like one measured on this
>    one. `_autocal_t` is stamped on apply, the same durable-trace trick as `_prepared_t`.
> 8. **✅ Registry hygiene — DONE 2026-08-18**, as part of the S27/S28 analysis. **28 → 24 rows**:
>    the duplicate saves of one run (S27 ×2, S28 ×3, S12 ×2) are gone, so no specimen is
>    double-weighted in an average any more; S27/S28 carry `infill_pct = 50` instead of the 100 the
>    infill-label defect wrote after a restart; the video runs carry VC1–VC7 labels; and every row
>    was re-scanned onto the new steepest-run E basis so the file is internally consistent.
> 9. **⬜ DECK — SLIDES FOR THE SMART FEATURES THAT HAVE NONE.** Agreed 2026-08-21. The SF grid now
>    runs SF1–SF19 (**16 rig-validated · 2 built · 1 hardware-blocked**), but five features have no
>    proof slide, and three of them had been sitting on the grid marked "plan" months after
>    shipping. Structure agreed with the operator:
>    ▸ **TWO OVERVIEW SLIDES, ~10 cards each** — SF1–SF10 and SF11–SF19 — so the whole feature set
>    can be walked through without the single dense grid. No images needed; build these first.
>    ▸ **THEN A COUPLE OF SLIDES PER MISSING FEATURE**, with screenshots the OPERATOR supplies:
>
>    | SF | Feature | Status | Screenshots needed from the rig |
>    |---|---|---|---|
>    | 11 | Auto-metadata link (capture ↔ CSV) | ✅ | the `# Capture:` CSV header · a `run.json` · the Save dialog with its registry / report tick-boxes |
>    | 12 | DIC auto-calibration | 🟢 | the auto-calibrate dialog **with its before/after table** · the manual-parameters dialog showing the live trackability readout · ideally a feed at a bad threshold (0 blobs) beside a good one (2/2) |
>    | 13 | Guided wizard | ✅ | the dock open EARLY (Connect is NEXT) and again LATE (most steps ticked) · the View ▸ Guided wizard menu item |
>    | 18 | Live Px₀ overlay | 🟢 | the feed at zero strain and again under load, with the frozen cyan pair and the live green pair separated. **⚠ BLOCKED — this is the same lighting problem holding up the overlay's rig validation, so it is the one item that cannot be shot today** |
>    | 19 | Video + image capture | ✅ | the Capture settings dialog · the CAP / REC indicator lit in the HUD |
>
>    ▸ **SF19's frames need no operator time** — one still from each of the three AVI styles
>    (raw / boost / speckle) can be pulled straight out of the S25/S26/S13 captures already on disk.
>    ▸ **SF19 is the subtle one.** p219–224 already exists but is a DATA-VALIDATION slide
>    ("frame capture, checked against the test data"); there is no slide that explains the FEATURE —
>    PNG + three AVI styles, adaptive speckle, multi-select, 0 dropped at 19.9 fps.
>    ▸ Estimated **12 slides → p248–259**. Overview pair first; the per-feature slides land as the
>    screenshots arrive, so the deck is never blocked on one of them.
>
> 11. **✅ THE MATERIAL RIDES WITH THE SETTINGS PROFILE — no per-test edit, nothing to revert.**
>    Landed 2026-08-24 after the operator rejected two earlier designs, each time for a better
>    reason than the last. **(a)** A third entry in the DIC specimen-mode dropdown — wrong,
>    because that dropdown selects optical POLARITY and a TPU specimen can be printed black or
>    white. **(b)** A Material combo plus a strain-cap box in the settings row — also wrong, and
>    not merely cluttered: **the material is not an independent choice.** It implies a preload,
>    a speed, and whether auto-stop makes any sense at all, and every one of those was still a
>    separate control the operator had to remember to change in step. Two set and one forgotten
>    is a wasted specimen. **(c)** So `Default` and `TPU` are now SETTINGS PROFILES, pinned to
>    the top of the Settings dropdown, and picking one moves everything the material implies at
>    once. `TestRecipe` gained `strain_cap_pct`; recipes written before it default to 25 %,
>    which is what every test on record actually ran at.
>    ▸ **Both starters are SEEDED, not tracked.** `recipes/` is gitignored because it also
>    holds the operator's own profiles, so `ensure_default()` writes Default and TPU on first
>    launch — otherwise a fresh clone would have had no TPU option at all and no way to reach
>    the 60 % window. It only writes what is MISSING, so a starter the operator has tuned is
>    left alone. Verified by seeding into an empty folder and by re-running it over an edit.
>    ▸ **The first TPU run (2026-08-24) died three samples in, and found two real bugs.**
>    `UTM_Test_20260824_142525.csv`: 124.8 s, crosshead **0.038 mm**, the whole file inside
>    −0.85..+0.74 N, status bar "Auto-stopped at fracture".
>    &nbsp;&nbsp;**(1) `LiveFractureDetector` fired in the load-cell noise band.** Every test in
>    it is RELATIVE to a running peak that starts at 0.0, so the first positive noise sample
>    (+0.29 N) became the peak, `armed` followed immediately (0.29 ≥ 0.3 × 0.29), and the next
>    negative sample read as a total load collapse. NOT TPU-specific — a stiff specimen simply
>    climbs out of the noise band fast enough to outrun it, which is why it had never appeared.
>    Fixed with an absolute `MIN_PEAK_N = 50` floor: ~60× the cell’s 0.27 N noise, 1.5 % of a PLA
>    fracture peak, and 0.6 MPa on an 80 mm² section — not a test result. The real 1416-sample
>    file now replays without firing.
>    &nbsp;&nbsp;**(2) The Fracture test button force-ticked auto-stop**, overriding the TPU
>    profile. It had to: the force/travel backstop AND the stall guard were gated on the same
>    checkbox, so switching the detector off silently removed the safety net. Now the backstop
>    and stall guard run on **every** commanded tension pull and only the DETECTOR is gated —
>    strictly more safety than before, since they previously depended on an operator tick-box.
>    ▸ **The ROI is now a profile field too, and TPU takes the full sensor width.** Px₀ is
>    ~1673 px and a clean marker ~60 px in radius, so the shipped 2348 px crop lets the centres
>    separate to **33.2 %** strain before one reaches the edge — while the travel backstop is
>    30 mm on an 80 mm gauge = **37.5 %**. The markers left the frame BEFORE anything stopped
>    the test, so the strain trace would simply have ended mid-pull with nothing visibly wrong.
>    `roi=[0, 988, 2448, 419]` (the whole 2448 px sensor width) moves that to **39.2 %**, past
>    the backstop. Height unchanged: as TPU necks the markers move toward the centreline,
>    inward. The 60 % strain cap is now the looser of the two limits — the ROI binds first, so
>    raising the cap further buys nothing without moving the camera.
>    ▸ `roi=None` had to be made to ACTIVELY restore the preset, not merely decline to change
>    it: `set_specimen_mode` is what reloads the preset ROI and it only runs when the mode
>    changes, so TPU → Default (both White) left the camera on TPU’s crop while Default’s own
>    field claimed it was following the preset. Caught by the round-trip assertion.
>    ▸ **A TPU pull now ENDS ITSELF at 25 mm** (`stop_travel_mm`, a new profile field).
>    Before this, a specimen that never fractures had only two ways to finish: the operator
>    judging the moment by eye, or the 30 mm backstop — which fires **Stop AND EStop** and is an
>    emergency halt, not a way to end a test. The target is a clean `Stop`, checked BEFORE the
>    backstop, and independent of the auto-stop checkbox because it is not fracture detection.
>    25 mm is 31 % nominal strain on an 80 mm gauge and sits clear of BOTH ceilings rather than
>    against either — the 30 mm backstop and the ROI’s 39 % — with 5 mm of headroom for the fact
>    that crosshead travel is not all gauge strain (some goes into the shoulders and grips).
>    A value at or beyond the backstop is refused with a console notice rather than accepted,
>    since it could never fire and the run would end on the emergency path instead.
>    ▸ The SETTING and the one-shot LATCH had to be separate. Clearing the setting on firing
>    would make `Save…` write `None` after a run and force a profile reload before the next
>    pull; not latching at all would re-fire on every sample, because the crosshead is still
>    sitting past the target. The latch resets on a direction change — the same hook that
>    re-arms the fracture detector for a new pull.
>    ▸ **What the TPU profile carries, and why each one.** Strain cap **60 %** — TPU reaches the
>    rig's ~34 % travel limit as REAL strain, and at the default 25 % the DIC would reject every
>    frame past that as a lost marker, silently, mid-pull. Preload **20 N**, not 300 — TPU is
>    orders of magnitude less stiff, so 300 N would tare away a large part of the elastic range
>    the comparison against PLA depends on. Auto-stop **OFF** — the detector watches for a
>    brittle load collapse and a drawing elastomer never produces one, so it can only misfire.
>    Gauge and section **unchanged at 80 mm / 80 mm²**, so the curves stay directly comparable.
>    ▸ **It fixed a bug the operator had already paid for by hand.** `utm_registry.py`
>    hard-coded `"material": "PLA"` on every record ever written and nothing in the UI ever set
>    it — which is how S30, S31 and S32, all PETG, entered the registry labelled PLA. The
>    material now travels profile → `CameraManager` → CSV header → `read_meta` → registry, with
>    the cap alongside it as `# DIC Strain Cap` so a run that aborted mid-pull is diagnosable
>    from the file. Headers with no `Material:` line fall back to PLA, which is what they were.
>    ▸ **Two bugs the checks caught in design (b) before it was discarded**, both of which read
>    perfectly in the source, and both worth remembering: `currentTextChanged` fires per
>    KEYSTROKE on an editable combo (typing "Aluminium" registered nine materials); and
>    `__init__` builds the settings row BEFORE it creates the `CameraManager`, so a restore that
>    looked correct set the widgets and pushed nothing — the box read 60 % while the DIC sat on
>    25 %, and a `hasattr` guard swallowed it silently. **Neither was visible without a check
>    that drives the widgets and then asserts on the CAMERA, not on the widget.**
>
> 10. **✅ CLOSED 2026-08-26 — `min_circularity` STAYS AT 0.40.** Introduced 2026-08-22 as a
>    temporary loosening for the PETG/TPU campaign, in `camera_manager.py` (the Black preset
>    AND the class default, which mirrors it). Kept by decision when that campaign closed,
>    rather than reverted to 0.50.
>    ▸ **What justifies keeping it.** The sweep below puts 0.40 mid-plateau, not on a cliff, and
>    nothing extra is admitted anywhere from 0.50 down to 0.25 (3+ blobs stays at 0.0 %).
>    What 0.50 bought — keeping grips and fixture edges out — is now carried by the
>    pair-plausibility guards and a frozen Px₀ rather than by roundness alone. If a run ever
>    admits a grip edge as a marker, this is the first thing to suspect.
>    ▸ **Why it was loosened.** The PETG dots have a crescent of overspray FUSED to the rim. The dot
>    is round; dot-plus-crescent is not. On capture `20260822_174204` marker 2 measures 17 131 px²
>    against a clean dot's 11 140 and scores **0.49–0.51 circularity across the run** — straddling a
>    0.50 gate, so noise flipped it either side frame by frame and 18 % of frames lost it.
>    ▸ **Threshold could not fix it:** NO fixed threshold yields exactly two blobs on those frames.
>    The failure is SHAPE, not brightness. Swept on the real capture, the 2-blob rate went
>    **0.50 → 81.8 %, 0.45 → 100 %, 0.40 → 100 %, 0.25 → 100 %**, with 3+ blobs staying at 0.0 %
>    throughout — so 0.40 is mid-plateau, not a cliff, and admits nothing extra.
>    ▸ **This remains a real loosening.** 0.50 earned its place; the decision is that the pair
>    guards and a frozen Px₀ now carry that job. Short runs, Px₀ set before the pull, and the
>    pair-plausibility checks are what make it safe — not the gate.
>    ▸ **The proper fix is STILL the SPECIMEN, and closing this item does not retire it:** mask around
>    each dot so overspray cannot land touching it, spray lighter from further back, and use MATTE
>    white — marker 2's core blows out to 255 from a specular sheen while its rim stays mid-grey. A
>    clean dot scores **0.76** and needs none of this.
>    ▸ Revert together with the note in `camera_manager.py`, and re-run `black_preset_check` and
>    `petg_tracking_check`.
>
> **✅ The E fit window — DECIDED AND IMPLEMENTED 2026-08-18.** `utm_analysis.analyze()` now
>   reports the **steepest straight run** as `E`, keeping the old fixed-window value beside it as
>   `E_fixed` so no historical number is lost. Registry re-scanned; deck **p223–224** (evidence) and
>   **p237** (what it moved) regenerate from the data. Measured over every run on record:
>
>   | rule for the window | mean E (100 %) | CV 100 % | CV 50 % | vs add:north TDS |
>   |---|---|---|---|---|
>   | ISO fixed 0.05–0.25 % | 2.56 GPa | 17.5 % | — | −10.9 % |
>   | fixed 0.05–0.40 % (the old rule) | 2.67 GPa | 13.2 % | 23.6 % | −7.0 % |
>   | **steepest straight run** | **3.02 GPa** | **8.5 %** | **12.6 %** | **+5.1 %** |
>
>   Scatter fell in BOTH materials, which is the case: a rule chasing noise would have raised it.
>   **UTS, ε_f, toughness and the anchor were verified bit-identical on all 20 runs** — a silent
>   change to UTS would have invalidated the campaign. σ_y moves (the 0.2 % offset line has slope E)
>   by −1.7 % typically and −10.2 % worst; its own scatter improves at 100 % (5.1 → 4.3 %) and is
>   flat at 50 % (7.7 → 8.0 %), so σ_y is unchanged in quality rather than improved.
>
>   Two implementation notes worth keeping: the R² floor is **relative** (within 0.0005 of the
>   straightest the record can offer, capped at 0.999) because an absolute floor alone fell back to
>   the fixed window on the noisier 50 % runs — two rules over one dataset is worse than either;
>   and the window search uses **prefix sums** for O(1) fits, because the naive version took ~5 s
>   per test behind the Generate-report button.
>
>   Still open, and NOT settled by this: whether the low-strain compliance is residual seating or
>   genuine PLA non-linearity. The 50 % pair was expected to help — a seating effect should not
>   scale with infill — but n = 2 per group cannot carry it. Also verify the ISO/ASTM clause numbers
>   against the source standards before publication. Prior art:
>   `documentation/decks/E_modulus_explained.pptx` slide 5 (the original S16 observation).
>
> **✅ MOTOR TORQUE CEILING — RESOLVED 2026-08-12. It was never a torque limit.** The load holders
> had worked loose, letting the crossheads sit out of alignment, so the motor was spending torque on
> binding instead of on the specimen. Re-aligned and re-tightened, the rig pulls **3.5 kN with no
> stutter**. Deck **p183** (root cause) and **p184** (the post-fix register).
>   ▸ The evidence was on disk before the fault was found: the same machine has fractured 100 %
>   infill at **3586–3826 N on 11 specimens** across three months — 11 of 11 straight through a
>   "2.6 kN ceiling". Decisive pair: **S15 stalled at 2.6 kN and S16 fractured at 3792 N on the SAME
>   DAY** (2026-07-28), +46 % on the same rig at the same speed.
>   ▸ Of the four ranked causes on the old T7 slide, the three electrical ones (Vref, thermal
>   derating, PSU sag) are **exonerated** — none of them can be intermittent between two consecutive
>   specimens. The mechanical one, ranked LAST, was it.
>   ▸ **Runs after 2026-08-12 are the reliable set**: S24, S25, S26, S27, S28, S12, S13 — 7 runs,
>   0 stalls, the five 100 % ones peaking 3693–3822 N. Both stalls on record fall before the line.
>   ▸ Still open, and unrelated: wiring the TMC2160's SPI to the ESP32 so motor current and thermal
>   status become a logged channel. Now a nice-to-have for diagnostics, not a blocker (§4).
>
> **✅ Cleared 2026-08-17/18 — GUI and pipeline, all bench-verified offscreen:**
> **Return to 0 mm** gated on SIGNED tension (50 N) instead of magnitude — `abs()` was blocking the
> one state the button exists for, since a fractured specimen reads −(tared away); an obstruction
> guard on the load CHANGE replaces the crash protection `abs()` was incidentally giving (`0ed4f79`)
> · **Generate report** saves into the specimen folder beside the CSV, asks where with that as the
> default, follows a filename you typed, follows an OPENED csv, and no longer nags to save after you
> have saved — that prompt was gated on `data_unsaved`, which every incoming load sample sets
> (`1c32a09`, `414f716`, `c870c28`, `478c194`) · **Tare DIC** is one click, no dialog; Calibrate Px₀
> keeps its confirmation · **Px₀ has exactly ONE owner — Calibrate Px₀** (`949ce20`, `6d41d49`).
> Tare DIC clears the console, the blob history, the measured rates and the strain queue and leaves
> the reference alone; **Prepare test tares DIC readouts + position + force**, reports the Px₀ in
> force and warns when none is set, but never captures one. This reverses `f945bb9` and removes the
> ordering hazard with it — nothing in Prepare touches Px₀, so it can no longer be frozen at 0 N by
> a force tare running first; the dependency now runs the other way (**Calibrate Px₀ BEFORE
> Prepare**) and the tooltip says so · **Black preset ROI** (`f122259`) ·
> **blob disambiguation** — a third qualifying blob no longer discards the frame, and a pairing
> nowhere near Px₀ is reported as a dropout rather than invented (`3f614dc`) · **speckle video
> polarity** rebuilt on specimen-mode change, which would otherwise have written a negative
> (`ef1b74b`) · **preload default 470 → 300 N**, matching what the rig is actually run at
> (`a339904`) · the central `reports/` folder deleted, nothing writes there any more.
>
> **Merge:** done — `snapshot/main-py-2026-08-12` is fully merged into `main` (0 commits behind) and
> `main` is pushed to `github.com/AdithyaSivakumar-3/UTM`.
>
> **✅ Cleared 2026-08-13** — live Px₀ overlay · GUI responsiveness (~700 → ~285 ms/s) · Release
> load split into "to preload" / "fully" · live stress-strain put on the report's basis (dropout
> rows, anchor, % units, downsampler pairing bug) · E-modulus explainer deck (5 slides) · **frame
> capture: PNG + AVI, 3 view styles, adaptive speckle, multi-select, folder choice, size warning** ·
> Px₀ ownership (Prepare test no longer moves it) · a QSettings bool that never restored false.

- ✅ **POSTERS — BUILT 2026-08-12, THREE EDITIONS from one content spec.**
  `documentation/scripts/generate_poster.py` → **`documentation/posters/`** (pptx + pdf for each):
  - **`Smart_UTM_poster_A0`** — conference wall poster, 3 columns.
  - **`Smart_UTM_poster_A4`** — conference handout, 2 columns. A genuine condensation, not a shrunken
    A0 (scaling A0 → A4 puts body text at ~5 pt).
  - **`Smart_UTM_progress_A4`** — progress report for a supervisor / manager. Different question,
    different poster: status · milestones · results · **the decisions needed from the reader** · next.
    The "asks" panel is the payload and carries the most visual weight after the headline.
  - **Features run in NUMERIC order SF1 → SF16 on every edition**, as a full-width band UNDER the
    column flow so they read left-to-right in order. They cannot go through the column flow: with 16
    cards it split them so SF7 landed at the top of column 3 while SF1 sat at the bottom of column 2.
    Status is carried by colour + chip instead of by grouping, so a **legend block is mandatory**.
  - **Rig photographs are background-removed cutouts** (`documentation/scripts/rig_cutouts.py`), which is why
    two of them can sit side by side without reading as a collage. Model choice matters: the default
    u2net is a salient-object model and keeps the wall and carpet visible THROUGH the frame openings,
    so the rig prints as a solid slab — **isnet-general-use** cuts the openings properly. A 15 px
    morphological close first heals the slender members it otherwise chews through.
  - **Layout follows the researched #evenbetterposter / "Generation-2" billboard format**, not a generic
    grid: attendee studies show 82 % prefer a billboard headline for the main message, but 67 % still
    prefer IMRaD for *rigor* — so METHODS ("How it works") and LIMITATIONS get full panels instead of
    sidebars. Headline: *"One specimen now yields a CURVE, not a point."*
  - Structure: title · billboard · 6-KPI strip · THE MACHINE (photo + labelled schematic) · WHY · HOW IT
    WORKS · 3 EVIDENCE panels with figures · 16 feature cards · LIMITATIONS.
  - **Feature cards carry no figure** — 16 thumbnails swamp even an A0 (first attempt overflowed 153 in
    into 100 in of column). Visual proof lives in the 4 evidence panels.
  - Every number is imported live from `sf9_data.py` + `registry.json`; nothing is typed by hand.
  - New assets: `documentation/figures/feat_prepare_specimen.png` + `feat_release_load.png` (SF2/SF8 had no proof
    figure at all — generated by `documentation/scripts/poster_assets.py`); `rig_photo.jpg`, `rig_photo_detail.jpg`,
    `rig_cut_full.png` / `rig_cut_detail.png` (background-removed cutouts of the 2026-08-12 rig
    photos) and `rig_schematic.png`.
  - **SF15/16 added to the registry below** — the test registry and the dead-DIC guard + hard backstops
    were built and validated but had never been carded. (SF17 was added and then RETIRED the same day.)
  - Layout engine notes: text heights are measured against the real Calibri metrics (a character-average
    estimate over-wrapped the 104 pt headline and left 1.5 in of dead space); section headers must be
    measured UPPERCASED because that is how they are drawn; columns are balanced by binary-searching the
    shortest feasible column height, since greedy packing left the last column a third empty.
- 🟡 **DECK — bring `documentation/decks/V6a_8_6_20_slides.pptx` up to current progress.**
  ✅ **SF9 built 2026-08-10 — 15 slides, pages 186-200, deck now 60 slides:** overview of all six modes (real measured signatures, not schematics) · 2 slides per mode (how it works + settings + **software limits**, then results with graphs and tables) · **T7 failure analysis** (why it stalled, ranked causes, mitigations). Numbers are computed by `documentation/scripts/sf9_data.py` from the rig CSVs and imported by the generator, so nothing on these slides is transcribed by hand.
  ✅ **Also built 2026-08-10/11 — deck is now 70 slides, pages 141-210:** T7 Vref answer (p200) ·
  two plain-English explainers for the T8 findings (p203/204) · SF3 "what Settings actually saves"
  (p205) · datasheet comparison rebuilt on the add:north TDS (p206) · two reference pages on strain
  and stress conventions (p209/210). `feat_dic_halt.png` regenerated from its CSV — it had no
  generator in the repo. Page numbers moved bottom-right (they were printing under the footer).
  ⬜ **Still to slide:**
  - ~~The 6 control modes~~ ✅ SF9
  - ~~Session 1–2 creep/relaxation/staircase~~ ✅ SF9 (measured overshoot +45.5/+46.8/+52.6 → +6.0/+4.8/+7.8 N)
  - ~~Cyclic T5/T6 → T6.3~~ ✅ SF9 (peak error 71 → 15 N; convergence 528 → 500 N shown)
  - ~~T7.2 staircase→fracture~~ ✅ SF9
  - ~~T8 progressive cyclic→fracture~~ ✅ SF9 (the crosshead-vs-DIC headline is the verdict banner on p198)
  - **Cross-protocol result:** T7.2 21.19 vs T8 21.38 MPa = 0.9 %, stated with the different-specimen
    caveat (that spread contains specimen scatter too; n=2 can't separate them).
  - ~~Motor torque ceiling / T7~~ ✅ SF9 p199 (dedicated failure-analysis slide)
  - **Workflow slides:** recipes (2 starter profiles), destructive-test confirmation, speed-scaled stall guard.
  - **Rebuild the SF grid (slide 169):** it shows only 8 cards and its banner still reads *"Engine ready to add 4 more modes: cyclic · staircase · relaxation · creep"* — those are all done now. Take it to **14 cards from §3c**, grouped built vs planned.
- ⬜ **BLACK-SPECIMEN DIC TEST — rig run, not just research.** Tracked in §5 below; repeated here so it is
  not lost among the reading tasks. Every specimen to date is WHITE; the "Black" DIC preset has never been
  exercised on the rig.

- ⬜ **RECORD THE FRACTURE TEST ON VIDEO — for independent analysis in the extensometer software at MOT.**
  **This is the only INDEPENDENT check of the DIC channel that exists.** Everything validated so far
  checks our DIC against itself or against the crosshead; nothing has ever compared it to a second,
  established strain instrument. If MOT's extensometer software reads the same strain from the same
  footage, the whole DIC chain — px/mm calibration, centroid algorithm, L₀ tare, engineering-strain
  definition — is corroborated from outside. If it does not, we find out before publishing.
  Two parts, and **the software half must land first** — a fracture run is one irreversible shot.
  1. **App — frame capture (does not exist today).** The camera pipeline computes centroids and throws
     the frames away. Add an opt-in **"Record frames"** toggle to the two fracture protocols that saves
     the raw Basler frames as an image sequence (or a low-compression video) next to the CSV, plus a
     sidecar mapping **frame index → PC and MCU timestamps** so any frame ties back to a load sample.
     Reuse the three-timestamp architecture already in the CSV.
     - **Compression is not free:** heavy H.264 destroys the sub-pixel correlation the extensometer
       software depends on. Prefer an image sequence or a lossless/near-lossless codec.
     - **Storage, at the current ROI** (2348 × 419 mono8 ≈ 0.98 MB/frame): ~10 MB/s at 10 fps, ~34 MB/s
       at the camera's 35 fps. A 200 s pull is therefore ~2 GB at 10 fps or ~7 GB at 35 fps. Fine as a
       one-off; do NOT leave it on by default.
     - Confirm the sensor is **global shutter** before relying on the footage — a rolling shutter shears
       a moving specimen and would corrupt the comparison.
  2. **Rig run + cross-check.** Pull one specimen to fracture with recording on, then run the same
     footage through the extensometer software at MOT and overlay its strain trace on ours.
     - Put a **scale reference in the same focal plane** as the specimen (the software needs its own
       px/mm; do not let it inherit ours, or the comparison is circular).
     - Keep the LEDs on and DC-driven — mains flicker aliases against the frame rate.
     - Record the ACTUAL frame rate, not the nominal one.
  **Done =** a fracture run whose footage loads in MOT's software, and a plot of their strain vs ours
  over the same interval with the deviation quoted — ideally within the **26 µε** noise floor in the
  elastic region, and with any divergence past yield explained (their gauge and ours may not span the
  same material).
  *(If this gets carded as a feature it becomes **SF18** — numbering is append-only, see §3c.)*

- 🟢 **Wire the control modes into the Motor-Control UI — DONE** ("Advanced test modes" segment, 6 modes incl. the two fracture protocols). ✅ **Recipes now store the mode + every mode's params** (`TestRecipe.mode` + `mode_params`, 2026-08-09) — one `_mode_widget_map()` drives both save and load. ✅ **All 6 modes rig-validated:** creep · relaxation · staircase · cyclic (T6.3) · staircase→fracture (T7.2) · **progressive-cyclic→fracture (T8, 2026-08-09 — 8 clean cycles, no false-fire, 25 % stiffness loss resolved, true UTS 21.38 MPa vs T7.2's 21.19 = 0.9 % apart)**. ⬜ Remaining: **deck slides** — scoped in §3a above.
### 3c. Smart-feature registry (SF numbers) — canonical list

The **SF number is a stable identifier, not a ranking or an ordering**. Numbering is **append-only**:
SF1–SF8 are already printed in the V6a deck (slide 169) and must never be renumbered. Poster, deck and
this file all cite the same numbers.

| SF | Feature | Status |
|---|---|---|
| 1 | DIC health HUD — live 2/2 · tracking % · jitter | ✅ rig-validated |
| 2 | Prepare specimen — one-click tare of position + force + DIC | ✅ rig-validated |
| 3 | Settings save / load (recipes) — reuse a whole setup | ✅ rig-validated |
| 4 | Generate report — one-click PDF + PNGs | ✅ rig-validated |
| 5 | Auto-stop at fracture — halts on load collapse | ✅ rig-validated |
| 6 | Strain-rate fracture test — constant *gauge* dε/dt | ✅ rig-validated |
| 7 | Stall guard — halts a frozen motor under load | ✅ rig-validated |
| 8 | Release load — controlled return through 0 to −preload | ✅ rig-validated |
| **9** | **Advanced test modes** — 6 closed-loop modes: cyclic · staircase · relaxation · creep · staircase→FRACTURE · progressive-cyclic→FRACTURE | ✅ **rig-validated 2026-08-09 (T8 closed the set)** |
| **10** | **Auto-preload** — speed-schedule 0.2→0.1→0.02 mm/s, stops at 1.03× target to offset PLA relaxation | ✅ rig-validated |
| **11** | **Auto-metadata + foldering** + one-click per-specimen deck (`utm_slides.py`) | ⬜ planned |
| **12** | **DIC auto-calibrate** — auto-exposure/threshold sweep · auto-follow ROI through the draw | ⬜ planned |
| **13** | **Guided workflow + live analysis overlay** — wizard · live E / predicted UTS / fracture flag · dashboard + audio cue | ⬜ planned |
| **14** | **Multi-marker Poisson / true Cauchy** — 4-marker preset, live ν | 🔴 hardware-blocked (optics) |
| **15** | **Test registry** — every run auto-indexed with E/σ_y/UTS/ε_f/toughness **and its force anchor** | ✅ rig-validated |
| **16** | **Dead-DIC guard + hard backstops** — freeze speed at 0.2 s of frozen strain, halt at 1.0 s; 10 kN / 30 mm caps | ✅ rig-validated |
| ~~17~~ | ~~Simulate-first harness~~ — **RETIRED 2026-08-12, never publish it as an SF.** It is a DEVELOPER practice, not a rig feature: `control_sim` is imported 0 times by `main.py` and has no serial/camera path, so an operator can never invoke it — and it is the one entry that made "every feature validated on the rig" false, since its 9/9 checks are all against a simulated spring plant. It lives on, correctly, as a METHODS bullet on the posters ("Simulated before hardware"). The number is burnt, not reused: the next feature carded is SF18. | — retired |

SF1–SF10 and SF15–SF16 (**12 features**) are built and rig-validated; SF11–SF13 are planned and SF14
is hardware-blocked. **SF17 was retired** — see the struck row above. **Group the poster by status, not by number** — the numbers are IDs, so a
status-grouped layout reads correctly without renumbering anything.

⚠️ **SF15–SF17 were added 2026-08-12** while building the poster — all three were built and in daily use but had never been carded. **SF17 was then retired the same day**: a card has to be something the OPERATOR uses on the rig, and a developer-only simulation harness is not that. Test for admitting a feature: *can the person running a test invoke it, or does it act on the machine during a run?* If not, it belongs in METHODS, not in the feature registry.

⚠️ **`utm_registry` (SF15) is also not wired into `main.py`** — it is a CLI you run (`scan`/`list`/`add`), not something that fires on save. It stays carded because it is operator/analyst-facing and produces a real artifact, but do NOT describe it as automatic; the automation is SF11, still planned.

⚠️ **SF10 (auto-preload) was not in the original SF1–SF8 set** — added here because the poster is meant to
show *all* smart features and auto-preload is a real, validated one that was simply never carded.

- ⬜ **p188 edge-tracking: track MINIMUM width, not the average.** The slide currently specifies
  "average width over 100s of rows". Necking is **local** — averaging over the gauge measures average
  thinning and systematically **under-corrects exactly where the correction matters** (at the neck,
  which is where fracture happens). Change the spec to the minimum width along the gauge before
  building it. Cheap to fix now, expensive after the rig is built. Reasoning on deck p210.

- ✅ **T6.4 / T6.5 / T7.3 DONE 2026-08-11 (S22).** Cyclic near yield validated: **12.3 px strain
  excursion vs T6.3's 3.6** (p189 predicted 13.1), **6 closed loops**, area **14.2→10.9 kJ/m³** and
  unload E **1.49→1.43 GPa** both falling monotonically at **R² ≥ 0.99**, peaks held to ±3.4 N.
  T6.4 lost the camera at t ≈ 145 s (45 % of frames) so only 3 loops survive there — **T6.5 is the
  slide-ready run**. S22 then pulled to fracture: **residual strength −8.5 % on tared load** after
  **16** cycles (8 in T6.4 + 8 in T6.5) at 79 % of UTS. Yield knee moved UP to 811-931 N (virgin 694) = load memory at the prior
  cycling peak. ε_f 3.60 %. Deck **p211-212**.
  - ⚠️ **CORRECTION 2026-08-12 — the TRUE-stress fatigue loss was quoted wrong.** "−6.1 %" appears in
    the registry and earlier notes but does not reproduce from its own inputs. Recomputed by
    `sf9_data.py`: T7.3 19.74 MPa vs **S18 21.19 = −6.8 %** (same protocol, so this is the correct
    baseline); vs the S18/S21 mean 21.285 = −7.2 %; vs S21 alone = −7.6 %. Virgin spread S18↔S21 is
    **0.9 %**, not 0.7 %. Always quote the loss **with its baseline**, never bare. The conclusion is
    unchanged — the loss is many times the virgin spread — only the number moves.
- ✅ **T9 — CREEP RESOLVED, 2026-08-11 (S23, 50 % infill), two runs.** Deck **p213-215**.
  - **Run 1, zero-load baseline (928 s, crosshead frozen, 20.57 ± 0.23 N):** drift **+0.2893 µε/s**
    (R² 0.896) = **+268 µε**; slope 95 % CI ±0.0019 µε/s, so subtracting it over 900 s costs only
    **±2 µε**. Half-slopes 0.345/0.277 (ratio 0.80) = **LINEAR**, the drift signature.
    **DIC noise floor re-measured: 26 µε** over a full 900 s window — the ±12 µε quoted elsewhere is
    a 40 s window and understates long-hold noise. Use 26 for any long-hold claim.
  - **Run 2, 600 N tared for 877 s:** load held **596.55 ± 1.30 N (±0.22 %)** = 7.46 MPa engineering /
    **11.30 MPa true** (anchor 307.1 N) = 53 % of UTS. Raw +1334 µε − 254 µε drift (19 % of raw) =
    **net creep +1080 µε = 41× the noise floor**. **Findley n = 0.484** and half-slopes 1.48 → 0.59
    µε/s (ratio 0.40) — decelerating primary creep, so the **pre-registered shape discriminator
    passes on its own**, independent of the subtraction. J = 0.863 → 1.008 GPa⁻¹ (+16.7 %).
    Crosshead had to advance **+172 µm** while the DIC gauge extended only +107 µm → only **62 % of
    crosshead motion was specimen** (the strongest DIC-necessity argument in the creep mode).
    DIC 100 % frames. **Bonus:** fixed-grip relaxation tail 598 → 582 N over 300 s (−2.8 %).
  - Open: creep/instantaneous 16.8 % is an **upper bound** (ε_inst tared at preload); n = 1 specimen at
    one stress level — a compliance CURVE needs 3-4 levels.
- ⬜ **T6.6 — the clean damage curve.** Fresh 50 % specimen, 400→1100 N, **12 cycles**, sine, 0.100 mm/s,
  ONE continuous run (no pause — E recovers across a rest). Baseline E on **cycle 2**, never cycle 1.
  Still the only missing piece: T6.4 lost DIC, T6.5 started already damaged, and E recovered over the
  40 min between them, so **D = 1 − Eᵢ/E₀ is not computable from the T6.4/T6.5 pair**.
- ⬜ **Infill label bug.** The CSV `Infill` header writes **100 %** after an app restart regardless of the
  setting — T6.4 / T6.5 / T9a / T9b all say 100 % on 50 % specimens (T7.3 is correct). It is a label that
  enters no calculation (area and gauge are entered separately), so **no measured number is affected**;
  the registry carries the true value. Fix the field's restart default in `main.py`.

### 3b. Longer-range features
- ✅ **Strain nomenclature settled (2026-08-11).** Everything user-facing now says **engineering**
  (ΔL/L₀): report axes, live plot legend, the strain-source dropdown and the `Eng ε:` readout. The
  dropdown branches on a stable `userData` key instead of display text — it was matching on the
  visible string, so a rename would have silently plotted the wrong array. **CSV columns
  `DIC_Cauchy`/`DIC_True` deliberately unchanged** (every past test and `utm_analysis` read them);
  the tooltip documents the mapping. See [[reference_addnorth_tds]] and deck p209.
- ⬜ **Multi-marker Poisson** — 4-marker preset in the dropdown, `detect_blobs`/`tare_dic`/`calculate_dic_strain` for 4 markers, new CSV columns (lateral strain / ν / current area / Cauchy), live ν readout. Needs a matte-black backdrop and/or a gauge-zoomed camera.
- ⬜ **Phase D — UX layer:** guided Connect→Calibrate→Mount→Prepare→Recipe→Run→Save wizard; live analysis overlay (live E / predicted UTS / fracture flag); glanceable dashboard + audio cue on fracture; event-annotation hotkey.
- ⬜ **DIC auto-calibrate (Phase C remainder):** auto-exposure/threshold sweep on Start Camera; auto-follow ROI (shift offset to keep markers centred through ductile draw).
- ⬜ **Auto-metadata + foldering** and **one-click per-specimen deck** (extract pptx builders → `utm_slides.py`).
- ⬜ **Deferred script migration:** `v6a_plots.py` / `v6a_analyze.py` → shared `utm_analysis` (when it grows a live-plotting return).

### Repo / version-control housekeeping
- ✅ **App source fully version-controlled (2026-08-09).** The 7 missing modules are now tracked: `camera_manager.py`, `serial_manager.py`, `camera_setup.py`, `roi_tool.py`, `widgets.py`, `build_exe.py`, `requirements.txt`. Verified every module the app imports is in git (the first pass walked only `.py` and missed the `.ui` file — see below). `requirements.txt` was also wrong — **opencv-python** and **pypylon** were missing entirely (the app could not be installed from it) and **scipy** was listed but unused; each entry now names the modules that need it. `main.py` stays uncommitted between explicit named snapshots, by choice.
- ✅ **`.gitignore` completed (2026-08-09).** Extended for the scratch artifacts that were burying real changes: debug frames (`binary_*.png`, `live_frame`, `test_*.png`, `utm_annotated`), output dirs (`full_frame_output/`, `setup_output/`, `test_images/`), the rig data folders (`8.6.3/`, `8.7/`, `8.6.20 …/`) and session video/photos. **Targeted patterns, not a blanket `*.png`**, so the `ui_help/` diagrams and the deck plots stay tracked (verified with `git check-ignore`). `git status` under `Software/UTM_PyQt6` went **36 untracked → 0**.
- ⬜ **`main.py` snapshot commit.** `main.py` is deliberately left uncommitted between explicit named snapshots (last: `a3b187f`, 2026-07-29). Since then it has accumulated a lot of unversioned work — advanced-mode UI (6 modes incl. both fracture protocols) · recipe mode/params wiring · speed-scaled stall guard · finer SetSpeed deadband · Release-load-to-true-zero (0.20 mm/s) · Prepare clears both plots · destructive-test confirm dialog w/ specimen echo · policy-log summary printer. **Take a snapshot when the current test campaign settles** (after T8 + deck).
- ⚠️ **Caught while doing this:** `ui/utm_mainwindow.ui` (53 KB Qt Designer file) was **untracked** — `main.py:48` does `uic.loadUi(...)` on it and `build_exe.py` bundles it via `--add-data`, so **a fresh clone could not have started the app**. Now tracked, along with the camera/DIC diagnostic scripts, the phase-8.6 validation suite and the `COMMANDS.txt` / `RECALIBRATE_ROI.md` docs.

---

## 4. Hardware constraints (not software — track separately)
- ✅ **NOT A TORQUE CEILING AT ALL — RESOLVED 2026-08-12. It was crosshead misalignment.** The load
  holders had worked loose, so the crossheads sat out of alignment and the motor spent torque on
  binding instead of on the specimen. Re-aligned and re-tightened, the rig pulls **3.5 kN with no
  stutter**. Deck **p183** (root cause) / **p184** (post-fix register); `documentation/scripts/torque_fix_data.py`
  recomputes the evidence from `registry.json`.
  - **The three electrical suspects are exonerated** — driver current (Vref), driver thermal
    derating, PSU voltage sag. Mechanical binding, which every earlier revision of this file ranked
    LAST, was the answer.
  - **Why only binding fits:** 100 % infill has fractured at **3586–3826 N on 11 specimens** across
    three months (mean 3726 ± 75 N, CV 2.0 %) — 11 of 11 straight through the supposed 2.6 kN
    ceiling. Decisive: **S15 stalled at 2.6 kN and S16 fractured at 3792 N on the SAME DAY**
    (2026-07-28), +46 % on the same rig at the same speed. Vref does not change between two
    specimens; thermal derating gets worse through a session, not better; PSU sag cannot let a
    *higher* load through. Only binding is intermittent, and it changes at a remount.
  - **The drivetrain arithmetic was right all along and pointed here:** 2 × 1.85 Nm × 20:1 into a
    5 mm lead gives **≥12.5 kN even at a pessimistic 15 % screw efficiency = 3.4× the 3.7 kN
    needed**, yet T7 stopped at 72 %. That gap was never electrical — it was friction in a
    misaligned load path.
  - 🟢 **Still worth doing, now for diagnostics rather than as a fix:** the drivers are **MKS
    TMC2160_57**, SPI Trinamic parts. Wiring CS/SCK/MOSI/MISO to the ESP32 would let motor current
    be set in code (`GLOBALSCALER` + `IRUN`) and **`DRV_STATUS` (otpw/ot) + StallGuard** be logged —
    which would have distinguished binding from derating directly instead of by inference. Deck p202.
  - ⚠️ **Historical note, kept deliberately:** revisions of this file have twice stated a wrong
    ceiling — first a flat "~2.6 kN" requiring reduced cross-sections (corrected 2026-08-09), then a
    "variable 3.2–3.4 kN torque capacity" (corrected 2026-08-12). Both were inferences from a
    symptom whose cause was mechanical. See `TEST_FAILURES.md` (S15) and memory
    `project_motor_stall_limit`.
  - **Runs after 2026-08-12 are the reliable set** — S24, S25, S26, S27, S28, S12, S13: 7 runs,
    0 stalls, the five 100 % ones peaking 3693–3822 N. Prefer them when a number must be defended.
- ⚠️ **Multi-marker transverse Poisson** infeasible on the current mini-dogbone (gauge too narrow for a transverse pair; elastic width change sub-pixel at ~20 px/mm). Needs a gauge-zoomed camera + dark backdrop, or a dedicated extensometer.

---

## 5. Research & documentation to-dos
- ⬜ **Chacón reference — measurement basis:** confirm whether Chacón et al. measured PLA properties on a **printed specimen** or on **raw filament / bulk material** — decides whether our (infill-corrected) values are directly comparable.
- ⬜ **Moisture effect:** check whether specimen / ambient **moisture** shifts strength or stiffness vs literature (PLA is mildly hygroscopic) — dry / condition specimens and compare.
- ⬜ **Camera-parameter sensitivity:** enumerate every camera parameter controlled in software (exposure, gain, threshold, ROI, px/mm, …) and study how varying each affects the DIC results and the **noise floor**.
- ⬜ **Black-specimen DIC check (100% infill):** every specimen tested so far is WHITE (black dots, DIC "White" mode). Print/mark a **BLACK** specimen (white dots, DIC "Black" mode) and confirm the camera tracks strain just as reliably. **Done = ** a full pull with 2/2 markers held to fracture, tracking % and L_px jitter no worse than a white specimen, and E/UTS within the white-specimen scatter. Needs a `camera_setup.py --mode white` pre-flight (the flag names the DOT colour, not the body). Also unblocks the matte-black backdrop that multi-marker Poisson wants (§3).
- ⬜ **Cross-validate the DIC against MOT's extensometer software** — record a fracture test and have a
  second, established strain instrument read the same footage. Full spec in §3a; repeated here because
  it is the one validation that comes from OUTSIDE this project.
- ⬜ **UTM instruction manual (for students):** short, crisp usage guide with clear photos of the rig + UI screenshots — Connect → Calibrate → Mount → Prepare → Run → Save → Report.

---

## 6. Key files
- **App:** `main.py` (control loop, live hook `on_load_cell_data`, CSV export, UI).
- **Engine/analysis:** `utm_analysis.py`, `control_policies.py`, `control_sim.py`, `utm_dic.py`.
- **Workflow/data:** `utm_recipes.py` + `recipes/`, `utm_registry.py` + `registry.json`, `utm_report.py`.
- **Records:** `TESTING_TODO.md` (test checklist), `TEST_FAILURES.md` (S15 stall), this file.

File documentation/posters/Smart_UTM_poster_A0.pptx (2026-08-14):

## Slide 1

SMART UTM — a tensile rig that runs, watches and stops its own tests

Jönköping University · School of Engineering — Materials & Manufacturing

One specimen now yields a CURVE, not a point.

12 automation features and 6 closed-loop test protocols, every one validated on the rig. Camera-based strain sits INSIDE the control loop, so the machine measures the specimen instead of measuring itself.

THE SMART FEATURES, SF1 TO SF16

12 / 16

smart features
built & validated

6

closed-loop test
protocols

17

runs auto-indexed,
13 specimens

± 1.3 N

force hold over
877 s

26 µε

DIC noise floor
(900 s window)

0.9 %

agreement between two
fracture protocols

THE MACHINE

The rig — built in-house, every control loop closed in software

Two steppers (1.85 Nm, 20:1) drive 5 mm lead screws against a fixed base. An ANYLOAD 3 t cell measures force; a Basler camera measures strain optically at 20.8 px/mm from two markers on the 80 mm gauge. The ESP32 runs STEP/DIR/ENABLE only and knows nothing of test protocols — every protocol, guard and measurement here lives in the PyQt6 app, closing the loop at ~11 Hz.

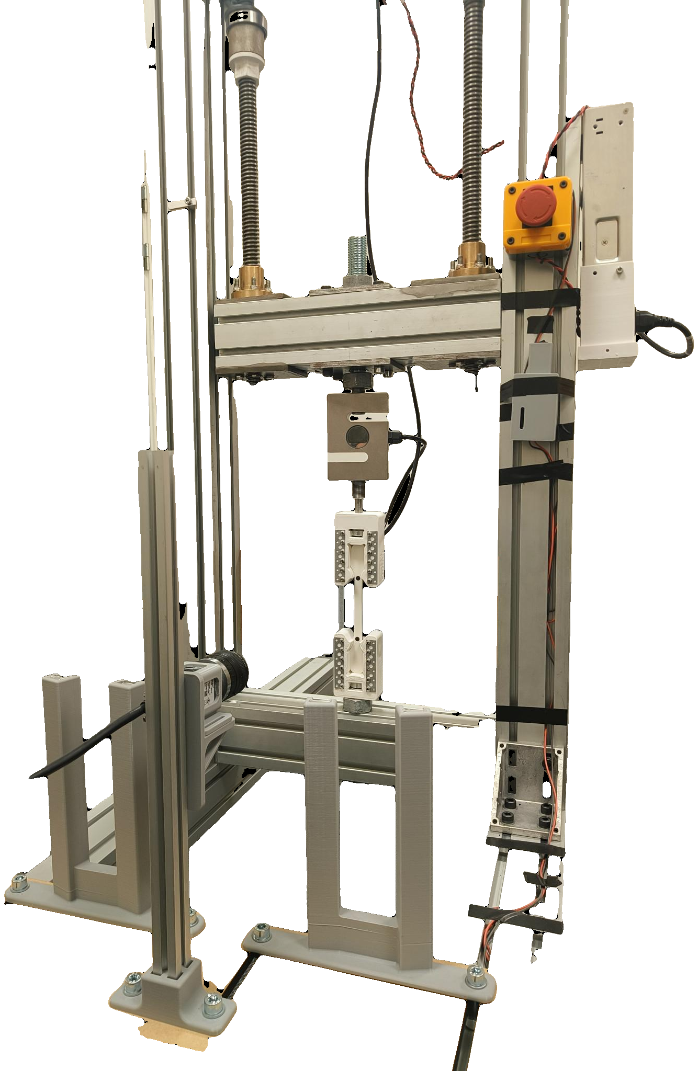
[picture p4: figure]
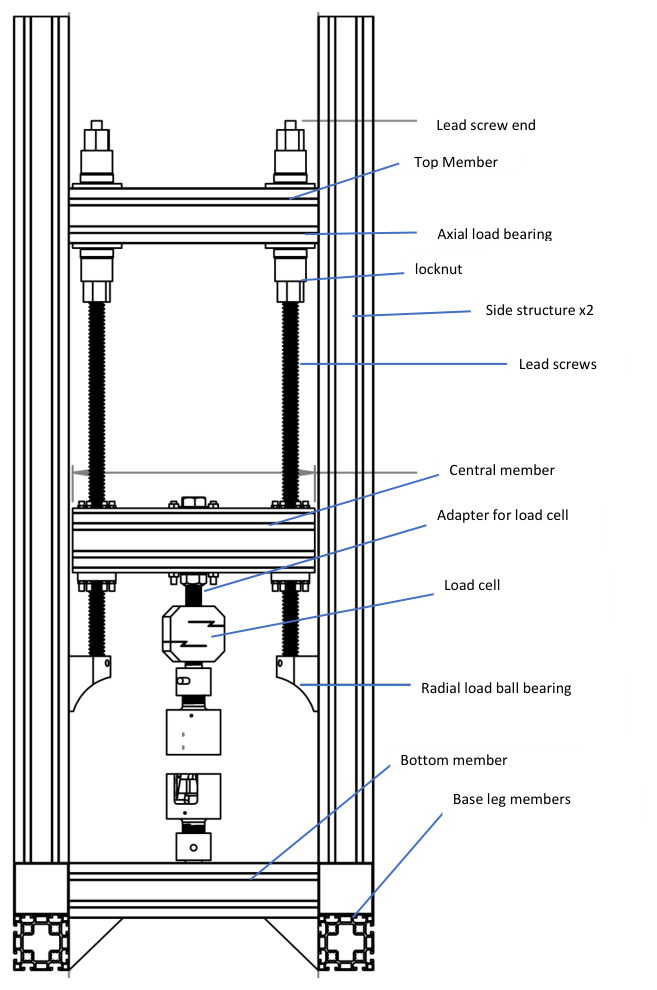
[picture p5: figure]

HOW IT WORKS

One control engine

All six protocols are one function called on every load sample (~11 Hz) with load, position and time-matched DIC strain in hand. A protocol only returns a speed — it cannot bypass the shared safety net.

Strain from the specimen

A camera tracks two markers; engineering strain is (L−L₀)/L₀ at 20.8 px/mm. The centroid resolves 0.1 px steps at ±0.02 px.

The machine reads STIFFER while the specimen SOFTENS

Progressive cyclic to fracture. Crosshead stiffness ROSE 744 → 777 N/mm as rig slack squeezed out, while the DIC-measured specimen modulus FELL 2.32 → 1.73 GPa, a 26 % loss. Read from the crosshead alone this test says the material is getting stiffer — the strongest argument for putting the camera in the loop.

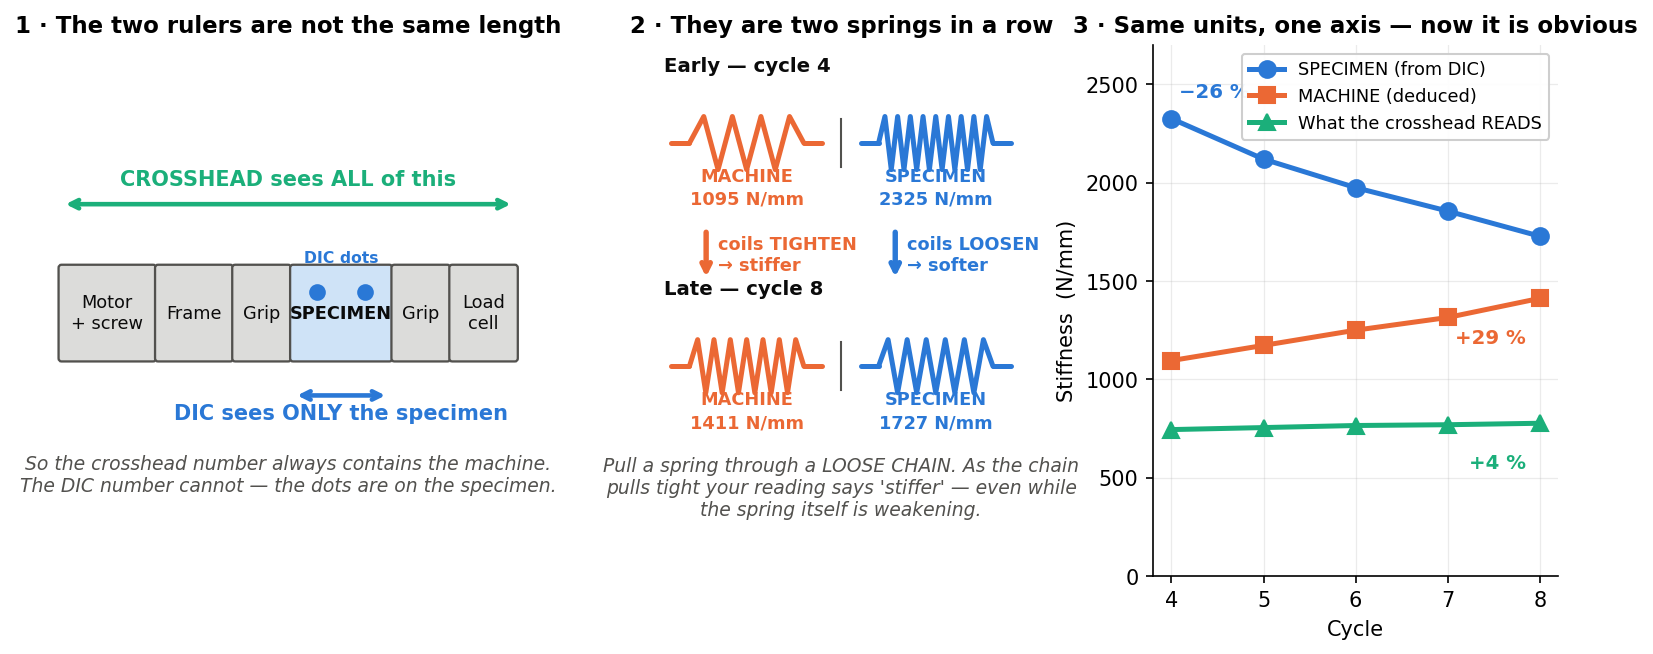
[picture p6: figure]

Simulated before hardware

Every policy is replayed against a spring plant and recorded CSVs — 9/9 checks pass before a specimen is risked.

Four safety layers

Load-collapse detector · stall guard (< 0.05 mm / 6 s under load) · 10 kN and 30 mm backstops · dead-DIC guard (freeze at 0.2 s, halt at 1.0 s). Guards are phase-aware, so the stall guard stays silent through an intentional dwell.

Creep, resolved — and separated from the instrument's own drift

Two holds, in order. A 928 s ZERO-LOAD baseline measured the rig's own drift at +0.2893 µε/s; the real hold then pinned 597 ± 1.3 N for 877 s at 11.3 MPa. Raw strain minus that slope leaves +1080 µε of creep — 41× the 26 µε noise floor — and it decelerates (n = 0.48), the criterion fixed BEFORE the run for telling creep from drift. Holding it took +172 µm of crosshead but only +107 µm of gauge: 62 % specimen.

One analysis library

The app, the reports and every figure compute E, σ_y, UTS, ε_f and the force anchor from the same code — a live readout and a published number cannot disagree.

WHAT THE AUTOMATION BUYS YOU

Six closed-loop protocols — every trace is real rig data

All six are one function behind one safety net; a protocol only chooses a speed. Two of them drive the specimen to destruction while interrogating it on the way — which is how one specimen yields a curve instead of a point. Two protocols taken independently to fracture landed 0.9 % apart on ultimate strength (21.19 vs 21.38 MPa) — on different specimens, n = 1 each, so that bounds protocol and specimen scatter together.

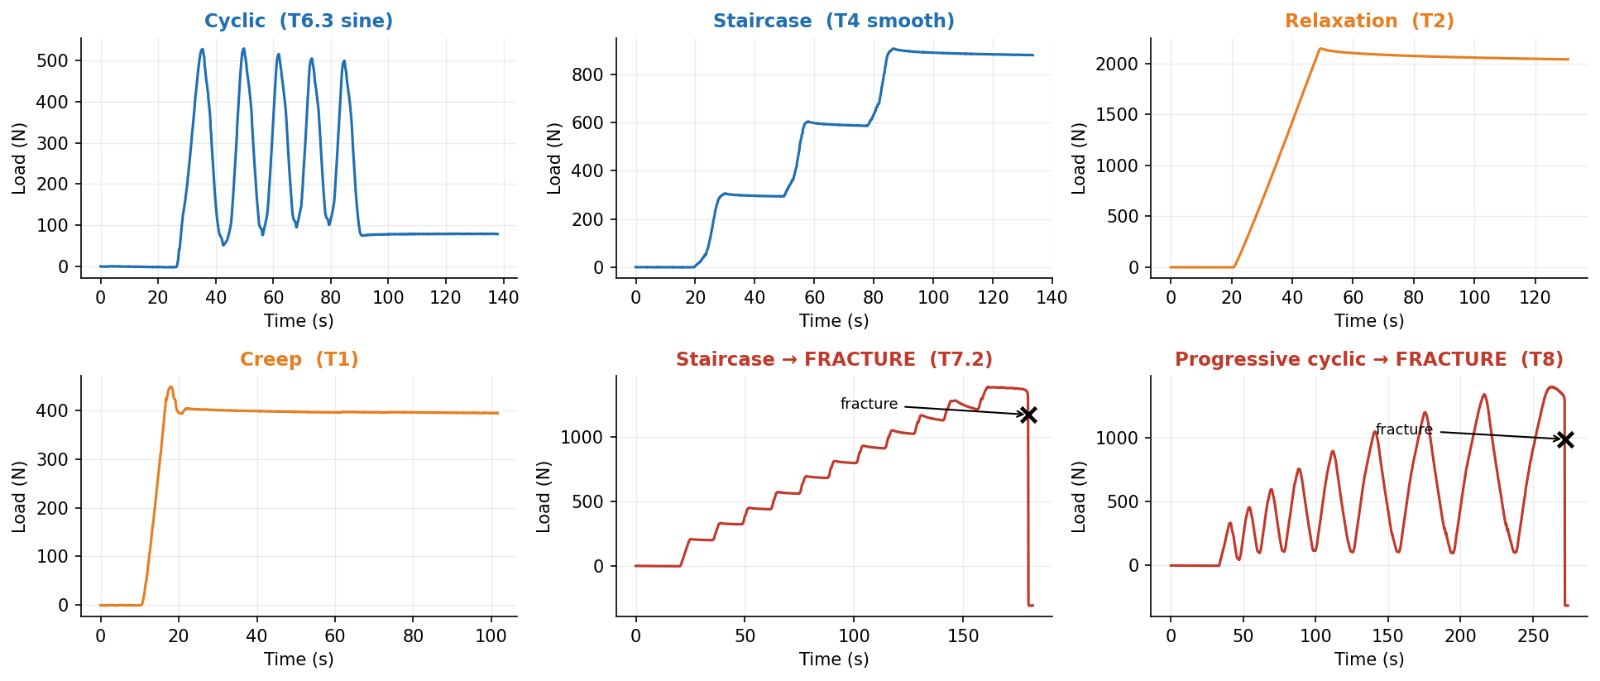
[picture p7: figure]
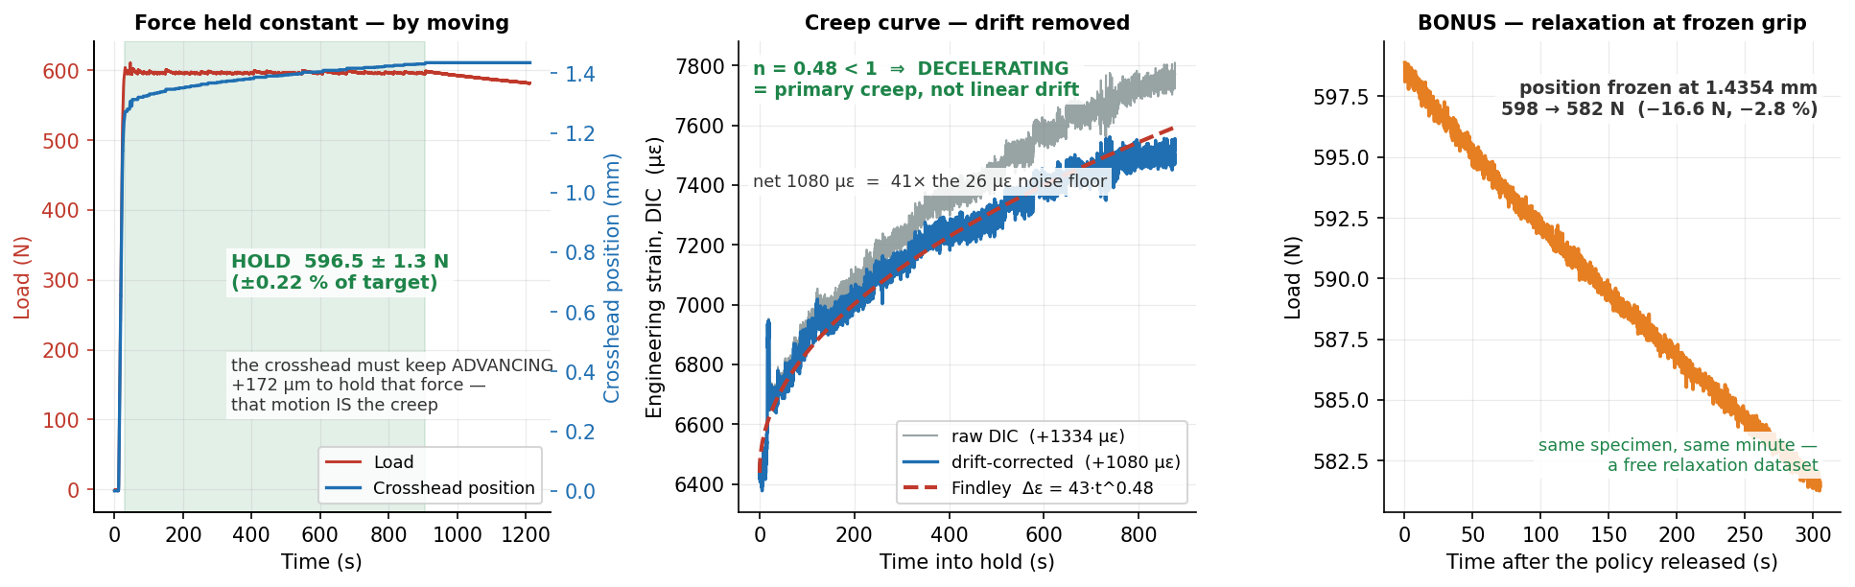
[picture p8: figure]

WHY AUTOMATE A TENSILE RIG

A conventional pull gives ONE modulus, ONE yield, ONE strength — and a human presses every button. Crosshead travel is not specimen strain, so the machine reports its own compliance as material behaviour. A destructive test is one irreversible shot. And nothing watches the run, so a stall, a lost marker or a fracture are all noticed late, by a person.

LIMITATIONS

Poisson's ratio is not measurable today

The gauge is too narrow: the elastic width change is sub-pixel at 20.8 px/mm. Every stress here is ENGINEERING (F/A₀), never 'true'.

No fatigue damage curve yet

One run lost the camera mid-way and its repeat started on an already-damaged specimen, and the modulus RECOVERED between them — so no valid E₀ exists.

Creep and fatigue are each n = 1

Both measurements are proven; the material constants are not. Creep needs 3–4 stress levels and fatigue needs repeats.

The motor's torque ceiling is variable

Normally 3.2–3.4 kN, but ~2.6 kN on one session. The drivetrain is rated far above that, so the cause is electrical — not the software.

built & rig-validated (12)
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

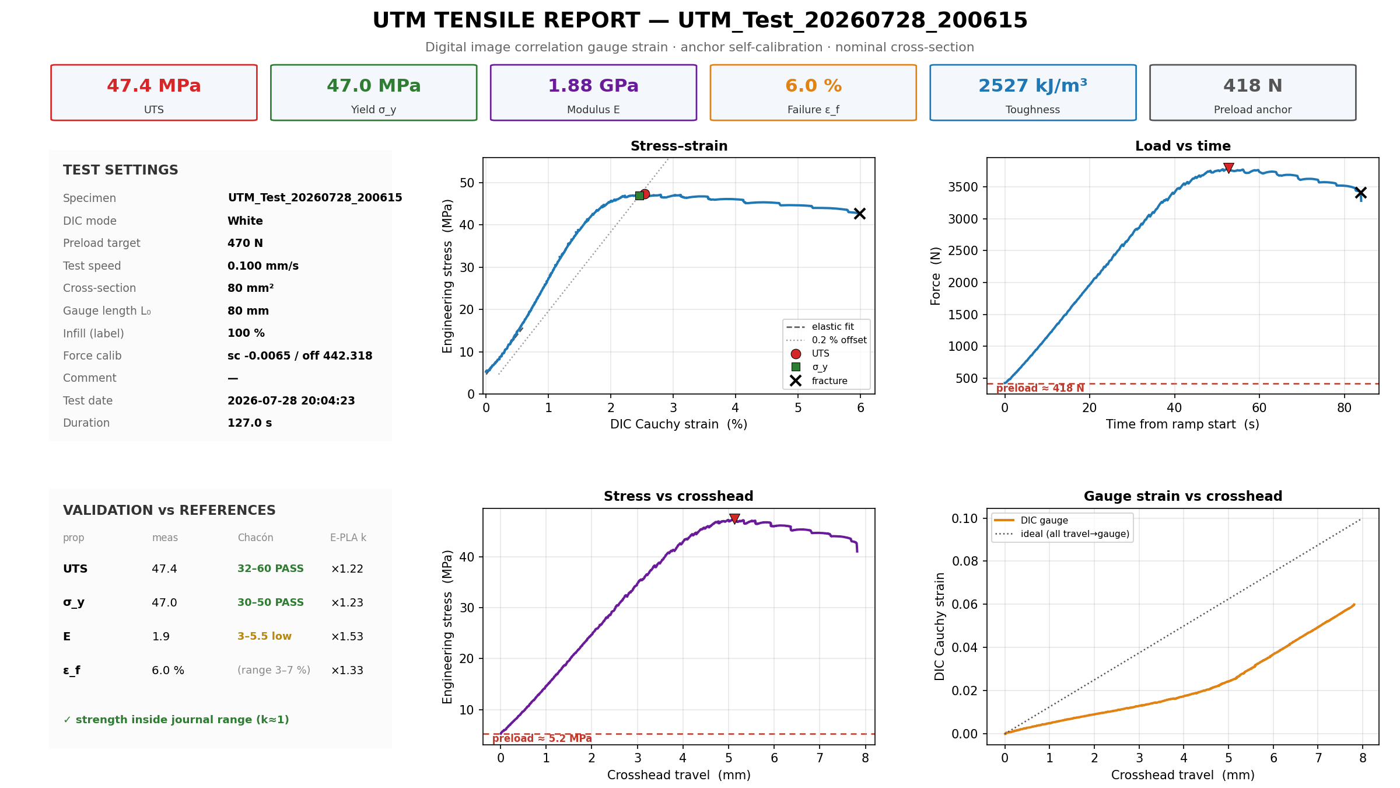
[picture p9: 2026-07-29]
images/features/feat_report_s16.png

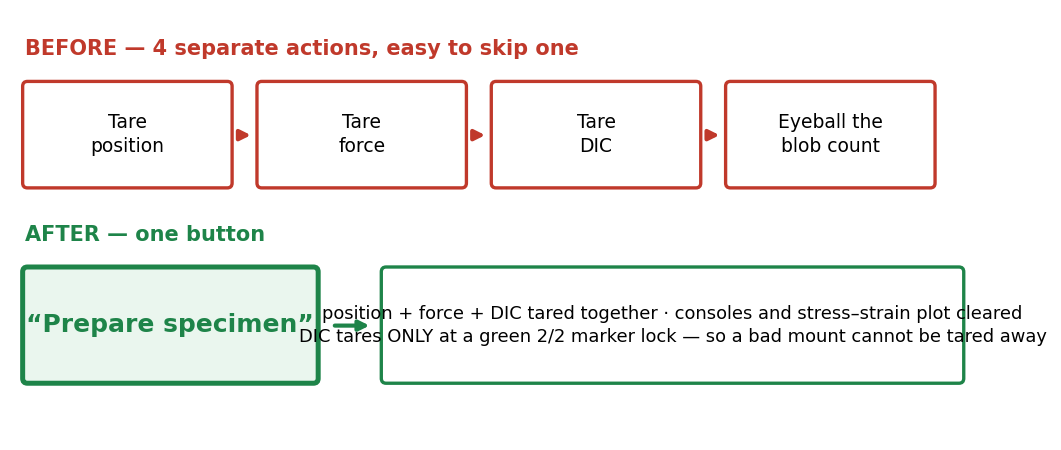
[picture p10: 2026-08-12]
documentation/figures/feat_prepare_specimen.png

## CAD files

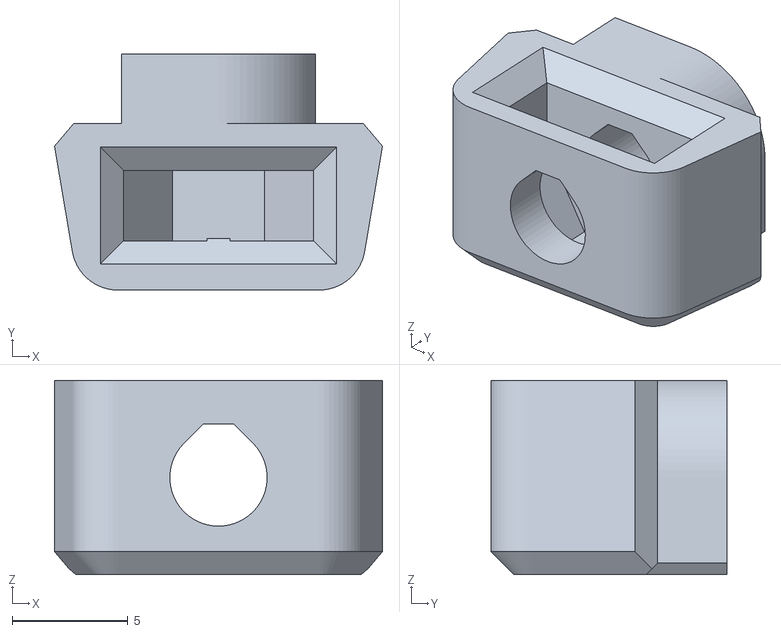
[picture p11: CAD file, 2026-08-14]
CAD/M4 Insert.stl
14.2 x 10.2 x 8.40

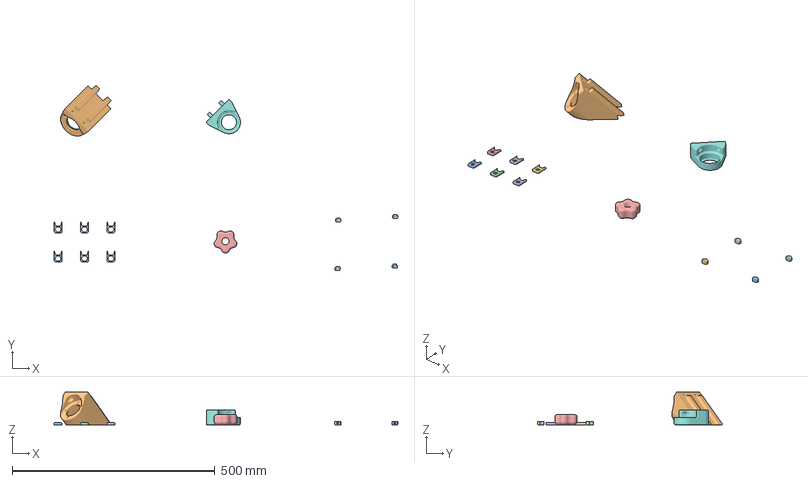
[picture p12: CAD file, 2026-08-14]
CAD/UTM.3mf
848.8 x 456.4 x 80.6 mm
TrackNut.stl x 6
MotorMountTop.stl
BearingMount.stl
M4 Insert.stl x 4
TR 22x6 Hand Screw 0.2.stl

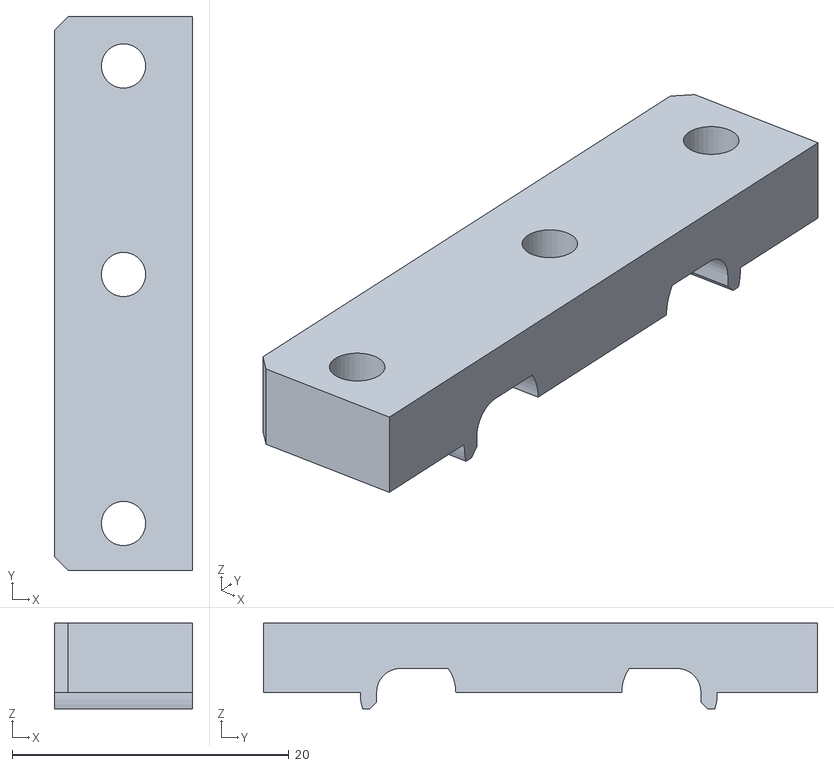
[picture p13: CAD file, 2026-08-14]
CAD/Clamp.stl
10.0 x 40.1 x 6.20

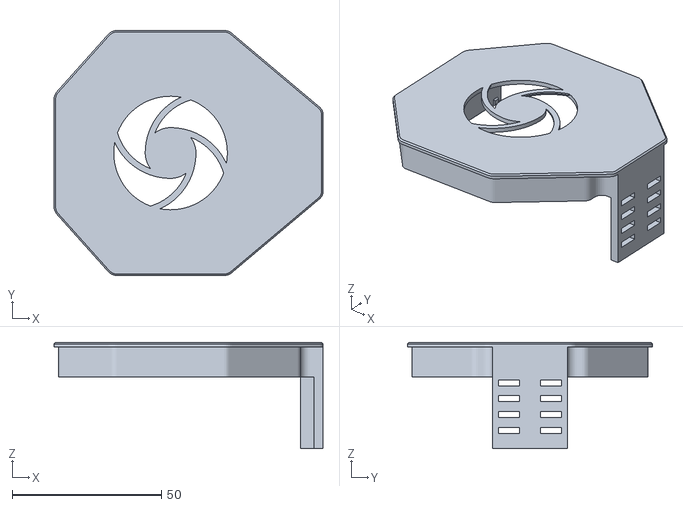
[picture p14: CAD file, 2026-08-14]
CAD/Nema 23 Cover.stl
90.0 x 82.0 x 35.5

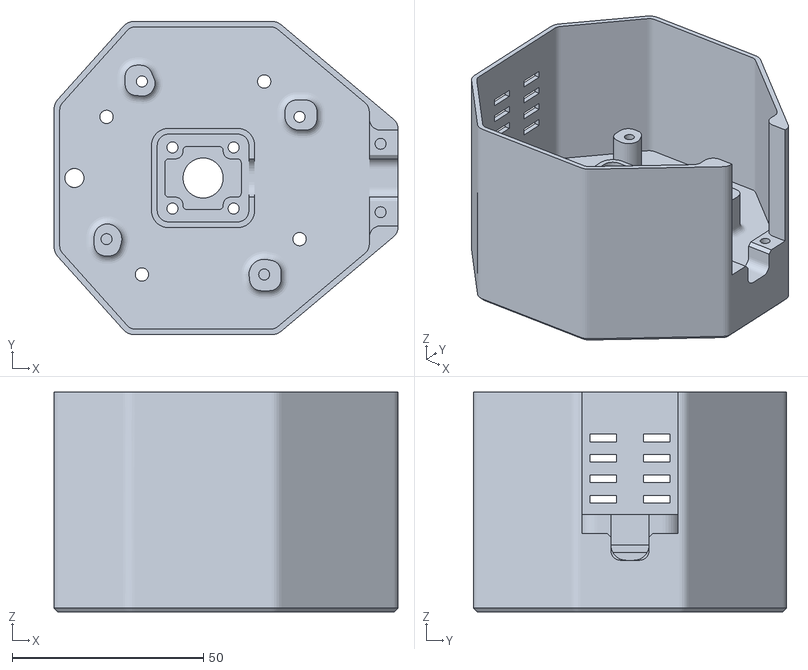
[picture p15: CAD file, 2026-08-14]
CAD/Nema 23 Baseplate.stl
90.0 x 82.0 x 57.5

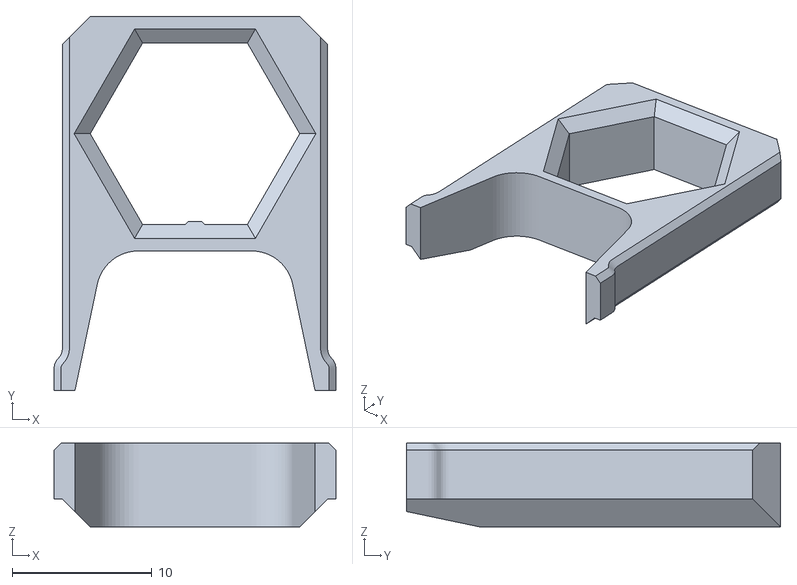
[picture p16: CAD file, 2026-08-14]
CAD/TrackNut.stl
20.2 x 26.8 x 6.00

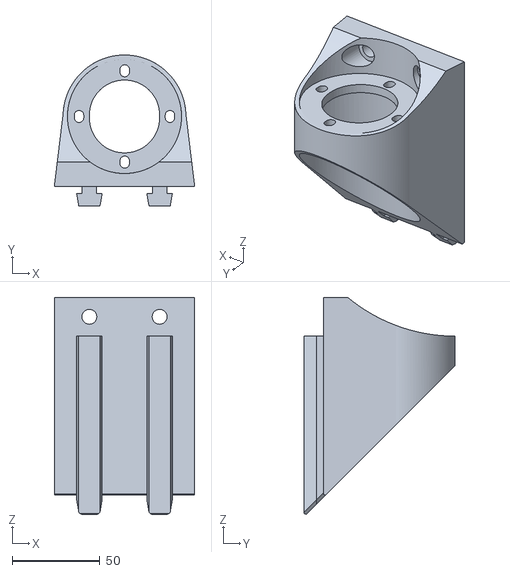
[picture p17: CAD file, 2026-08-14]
CAD/MotorMountTop.stl
80.0 x 86.0 x 123.6

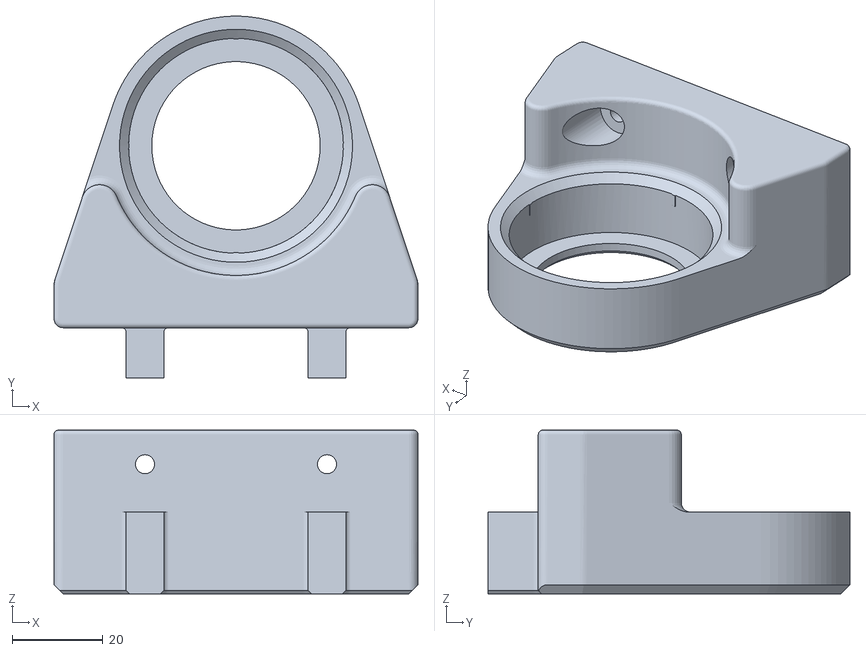
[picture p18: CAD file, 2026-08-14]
CAD/BearingMount.stl
80.0 x 79.5 x 36.0

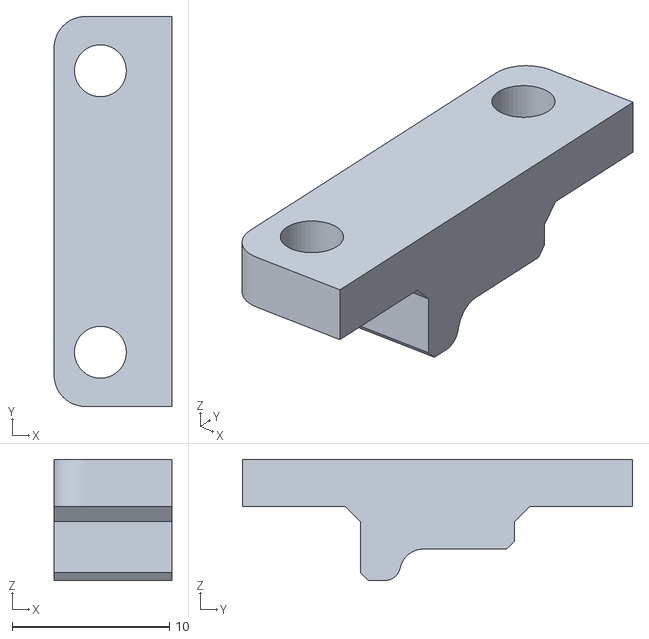
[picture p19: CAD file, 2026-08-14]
CAD/MKS Clamp.stl
7.50 x 24.8 x 7.70

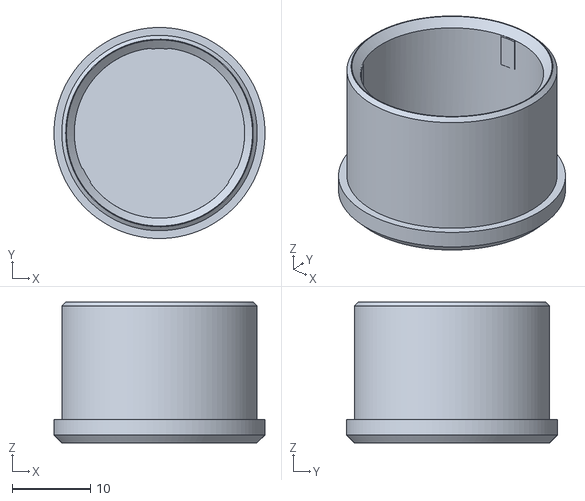
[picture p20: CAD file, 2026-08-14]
CAD/TR Insert.stl
27.0 x 27.0 x 18.0

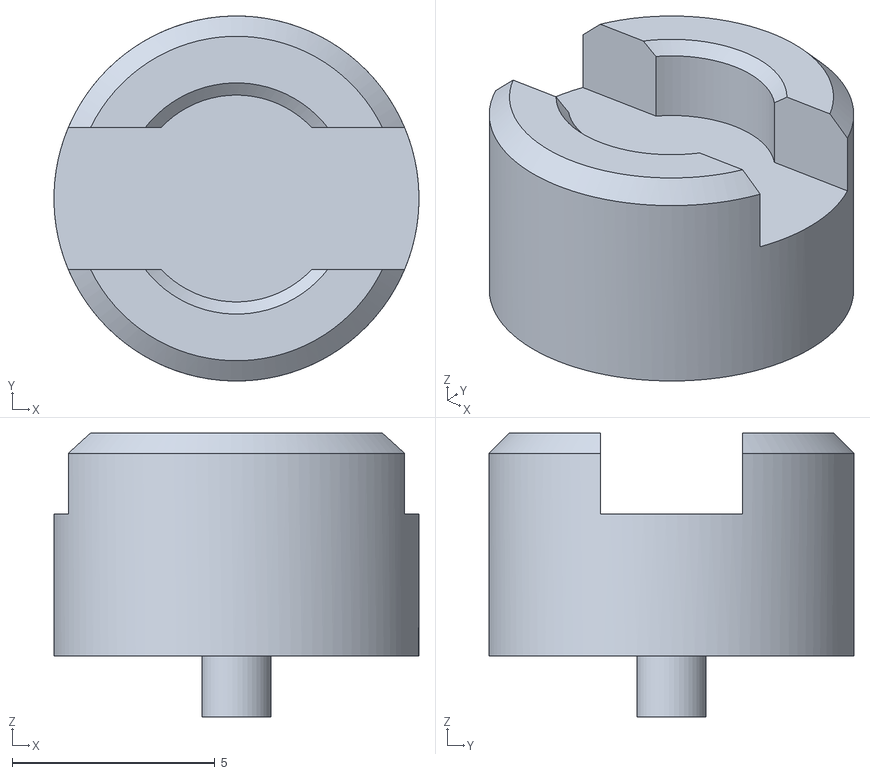
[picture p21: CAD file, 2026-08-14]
CAD/CenterPegg.stl
9.00 x 9.00 x 7.00

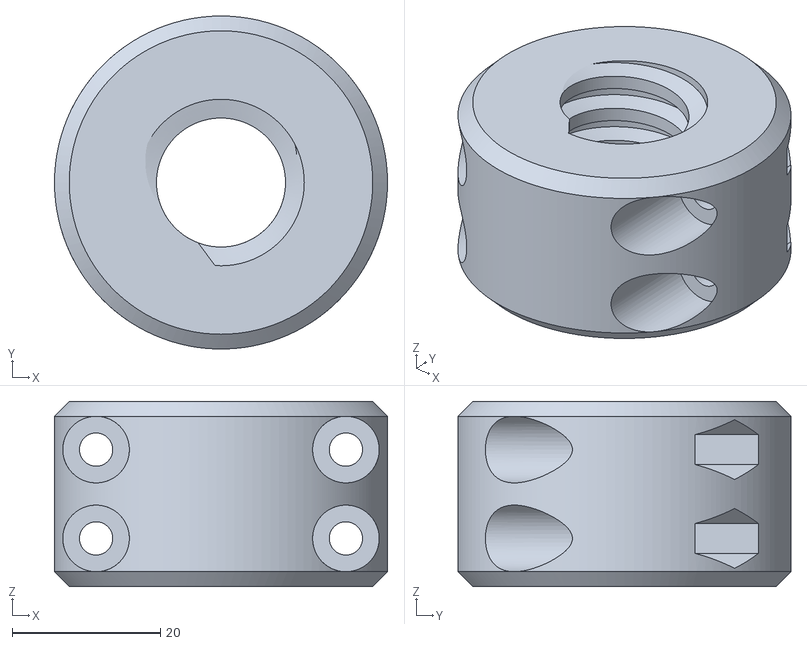
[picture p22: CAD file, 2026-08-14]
CAD/TR 22x6 Hex Clamp.stl
45.0 x 45.0 x 25.0

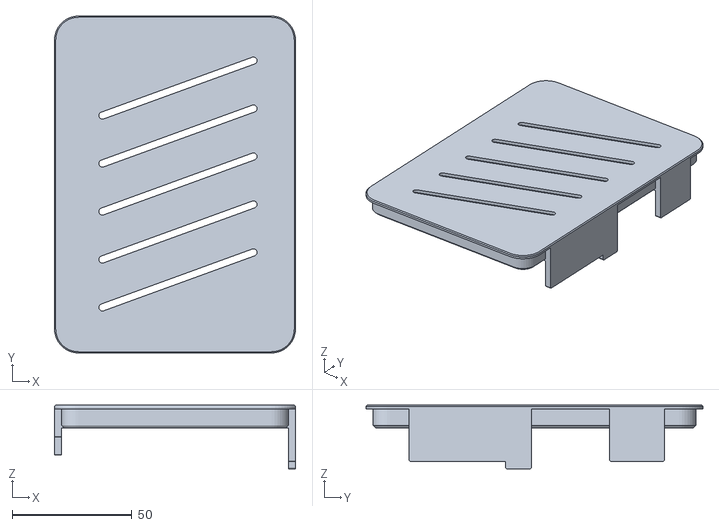
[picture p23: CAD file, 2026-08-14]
CAD/Cover.stl
100.5 x 140.5 x 26.5

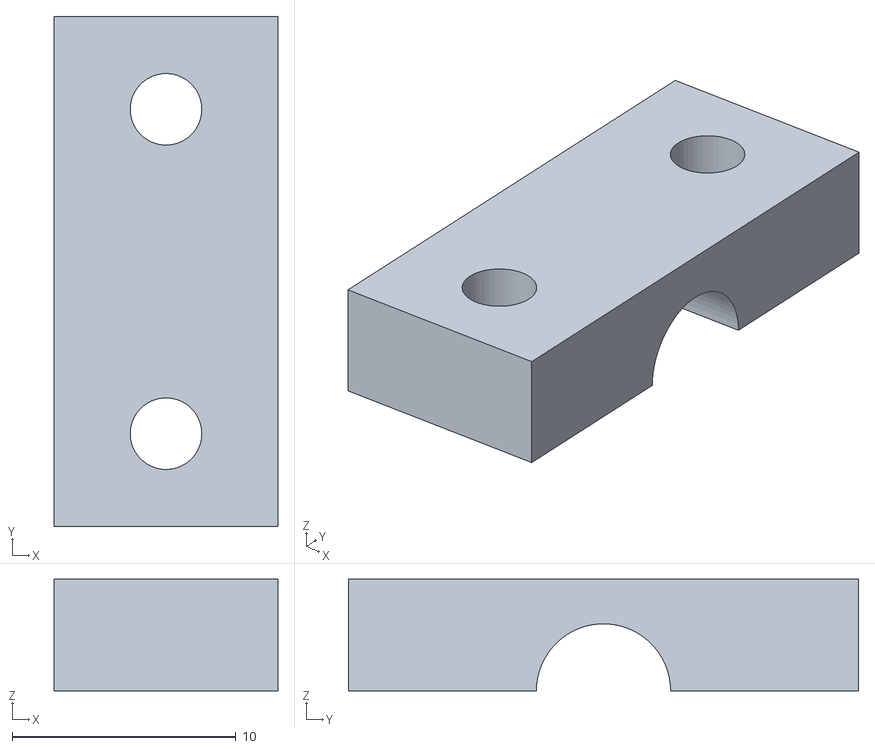
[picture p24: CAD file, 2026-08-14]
CAD/Clamp2.stl
10.0 x 22.8 x 5.00

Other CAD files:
CAD/ElectronicsBox.stl
CAD/TR 22x6 Hand Screw 0.2.stl
CAD/TR 22x6 Hex Nut 0.1.stl
CAD/Thrust Washer.stl

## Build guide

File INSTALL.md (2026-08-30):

# Installing the UTM software

For students. Windows 10 or 11. Takes a few minutes.

You do **not** need Git, Python, or the 2 GB Basler pylon Suite. The installer
brings its own Python and the camera driver ships with it.

## Install

Open **PowerShell** (Start menu, type `powershell`) and paste this one line:

```powershell
irm https://raw.githubusercontent.com/cenmir/UTM/main/deploy/get.ps1 | iex
```

Press Enter and wait. It downloads the app, sets up Python, and puts a
**UTM Control** icon on your Desktop.

Partway through, Windows asks for administrator with a UAC prompt. That is the
camera driver — 1.8 MB, signed by Microsoft. It is the only step that needs
admin, and the whole install is the only time you need it.

- **Your laptop will get the camera plugged into it?** Click Yes.
- **Not sure?** Click Yes anyway. It is harmless on a machine with no camera.
- **Definitely no camera?** You can click No. Everything else still works.

## Run it

Double-click the **UTM Control** icon on your Desktop.

The app runs on any laptop, with or without the rig. Without hardware you can
still open a CSV, plot it, crop it, and measure strain from a recorded video in
the **DIC Post-Processing** tab. You just cannot start a test.

## Update

Run the same one-line command again. Your `.venv`, your recipes, and your test
data are kept — the installer only replaces the program itself.

## If something goes wrong

**"running scripts is disabled on this system"** — PowerShell is locked down.
Run this once, then retry the install:

```powershell
Set-ExecutionPolicy -Scope CurrentUser RemoteSigned
```

**The camera is not found.** You probably declined the UAC prompt. Install the
driver on its own:

```powershell
powershell -ExecutionPolicy Bypass -File "$HOME\UTM\deploy\install_driver.ps1"
```

Then unplug the camera and plug it back in. Use a **USB 3** port — the blue one.

**Still not found.** Open Device Manager and look for an unknown USB device. If
the camera appears there, the driver did not take; re-run the line above.

**No COM port for the rig.** Check the USB cable, then press **Scan for COM
ports** in the app. The rig shows up as `USB2.0-Serial`.

## Installing somewhere else

```powershell
$env:UTM_DEST = "D:\UTM"     # default is C:\Users\<you>\UTM
$env:UTM_NO_DRIVER = "1"     # skip the camera driver entirely
irm https://raw.githubusercontent.com/cenmir/UTM/main/deploy/get.ps1 | iex
```

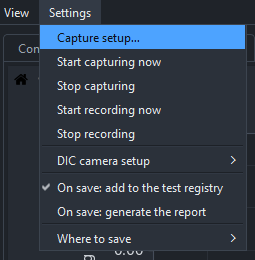
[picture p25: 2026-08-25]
documentation/figures/UTM_capture_setup2.png

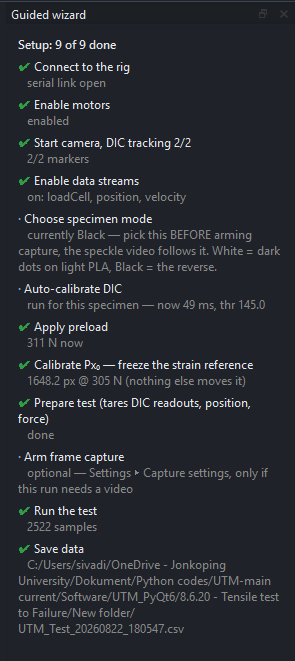
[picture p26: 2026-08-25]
documentation/figures/UTM_GuidedWizard.png

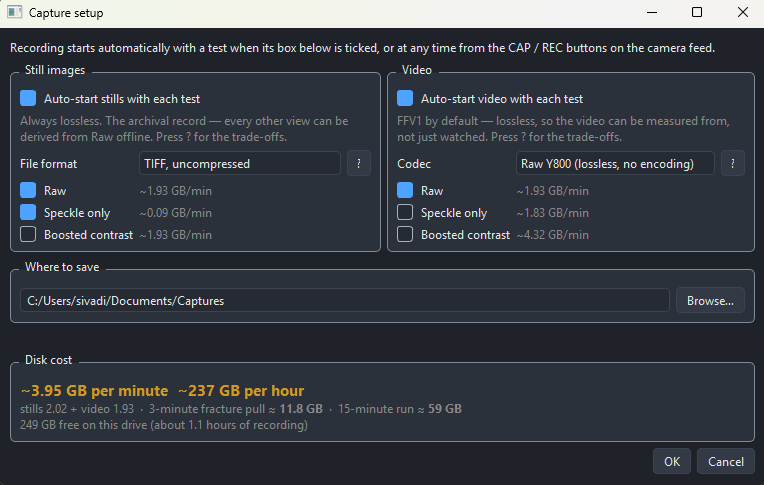
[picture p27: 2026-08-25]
documentation/figures/UTM_capture_setup.png

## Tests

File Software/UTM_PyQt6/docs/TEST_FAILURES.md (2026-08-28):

# UTM — Test Failure Log

Records of tests that did NOT complete, with data-backed analysis and predicted causes.

---

## S15 — 2026-07-28 — crosshead BIND at ~2.6 kN (no fracture)  ✅ RESOLVED 2026-08-12

- **Specimen:** S15, 100 % infill, spray markers (V2 batch). CSV: `8.6.20 - Tensile test to Failure/Specimen_S15_V2_Spray/UTM_Test_20260728_182021.csv`.
- **How run:** preload 500 N → release → **Fracture test** button (0.1 mm/s tension, auto-stop armed).
- **Symptom:** heavy jitter / whole machine shaking; crosshead stopped advancing; operator had to Stop manually and release down.

### What the data shows
| t (s) | Force (N) | pos (mm) | pos rate (mm/s) |
|---|---|---|---|
| 60→120 | 0 → **2592** | 0 → 4.69 | ~0.10 (normal) |
| 140 | 2555 | 4.750 | 0.003 |
| 160→250 | 2514 → 2442 | 4.76 → 4.82 | **≈ 0 (frozen)** |

- Normal pull to **2592 N (32.4 MPa)** by t≈120 s, then the crosshead **froze**: 4.69 → 4.82 mm over the next **130 s** while commanded 0.1 mm/s. Force then **relaxed** 2592 → 2442 N (constant-strain relaxation).
- **32.4 MPa ≪ ~46 MPa** where a V6 100 % specimen fractures → this was **NOT a fracture.** The motor stalled — but against a binding drivetrain, not against the specimen. See root cause below.

### ✅ ROOT CAUSE — RESOLVED 2026-08-12. It was NEVER a torque limit.

**The load holders had worked loose**, letting the crossheads sit out of alignment, so the motor
spent its torque on binding instead of on the specimen — the trapezoidal screws were biting.
Re-aligned, re-tightened and the screws lubricated, the rig pulls **3.5 kN with no stutter**.
Deck **p183** (root cause) and **p184** (the post-fix register); full write-up in `ROADMAP.md`.

- **The evidence was on disk before the fault was found.** The same machine has fractured 100 %
  infill at **3586–3826 N on 11 specimens** across three months — 11 of 11 straight through the
  supposed "2.6 kN ceiling". Decisive pair: **S15 stalled at 2.6 kN and S16 fractured at 3792 N on
  the SAME DAY** (2026-07-28), +46 % on the same rig at the same speed.
- **The three electrical causes below are exonerated** — none of them can be intermittent between
  two consecutive specimens. The mechanical cause, ranked LAST at the time, was it.
- **Runs after 2026-08-12 are the reliable set**: S24, S25, S26, S27, S28, S12, S13 — 7 runs,
  0 stalls, the five 100 % ones peaking 3693–3822 N.

**The machine is rated to ~15 kN** (see `PROJECT_REQUIREMENTS.md`): 2 × Nema 23 at 1.85 Nm through
20:1 gearboxes = 37 Nm per Tr22x5 screw, and the Anyload 101BH-3t cell reads to 29 kN. A 3.8 kN
fracture is ~25 % of capacity. **There is no force ceiling anywhere near a PLA tensile test, at any
infill.** A recurrence means the mechanics have been disassembled and reassembled wrong, or the
screws have run dry — not that the motor is undersized.

### Original root cause (predicted 2026-07-28 — SUPERSEDED, kept for the record)
- **Motor/drive hit its usable force ceiling (~2.6 kN) and stalled.** A stalled stepper skips steps → the shaking. 100 % infill at 80 mm² needs **~3.7 kN** to fracture — beyond reach here.
- Earlier V6 100 % runs fractured at ~46 MPa ≈ **~3.2 kN at the load cell**, so the motor *has* pulled harder before. Stalling ~20 % lower this time ⇒ **derating**, most likely:
  1. **Thermal** (top suspect) — motor hot after the preload cycle + a long 250 s pull.
  2. **Driver current (Vref)** set below spec.
  3. **Mechanical binding / friction** on the screw or rails.
- Load cell is NOT the limit (ANYLOAD 3 t / 29 kN). **The motor is the bottleneck.**

### Software check
- **Fracture test code reviewed — no bug.** It correctly commanded a 0.1 mm/s tension pull; the load rose normally. Auto-stop correctly did **not** fire (no load collapse = no fracture — a stall is a different failure mode).

### Actions taken / recommended
- ✅ **Stall guard added** (software): during an auto-stop / Fracture-test pull, if the crosshead advances **< 0.05 mm in 6 s** while under load (> 200 N), it auto **Stop + E-Stop** and pops up "Stall guard activated". Would have halted this in ~6 s instead of 130 s of shaking.
- ✅ **Before re-test:** ~~cool the motor, check Vref~~ — **check crosshead alignment, load-holder tightness and screw lubrication.** That was the fault.
- ~~⏳ **Specimen design:** for 100 % infill, use a smaller cross-section so fracture force stays under ~2.6 kN.~~ **WITHDRAWN 2026-08-12** — there is no 2.6 kN ceiling. 80 mm² at 100 % infill is correct and has fractured 11 times.
- ⏳ **Re-test** with a **fresh** specimen (S15 is now cycled) after cooldown.

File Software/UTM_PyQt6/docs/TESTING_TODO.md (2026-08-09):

# UTM — Rig / GUI Test Checklist

Features built in the app (`main.py`, kept unversioned) that need a **camera + rig** pass.
They compile and their logic is unit-tested offline, but only the machine can confirm behaviour.
Tick each off after testing; note anything that misbehaves.

---

## 1. DIC health HUD  ✅ CONFIRMED 2026-07-27  *(Phase C)*
A coloured badge on both test tabs: `DIC OK/WARN/BAD · N/2 markers · track % · jitter px`.
- [x] Start the camera with a good 2-marker specimen → badge goes **green "OK · 2/2 · track 100%"**.
- [x] Cover / occlude one marker → badge goes **red "BAD"** and shows `1/2` or `0/2` within ~1 s.
- [x] Uncover → returns to green.
- [x] Nudge the rig / add vibration → **jitter px** rises (amber "WARN" if it gets bad).
- [x] Stop the camera → badge greys to "DIC —".
- **Result:** PASS — live badge tracks markers and flips red on dropout.

## 2. Prepare specimen (one button)  ✅ CONFIRMED 2026-07-27
- [x] Click **Prepare specimen** → console logs `tared: position, force, DIC`.
- [x] Confirm force, position and DIC strain all read ~0 afterwards.
- **Result:** PASS — clears both consoles + the stress-strain plot, then tares position + force + DIC
  (DIC only when 2/2 markers are tracked; honestly reports "DIC skipped" otherwise). Load plot kept.

## (bonus) Release preload  ✅ CONFIRMED 2026-07-27
- [x] Preload → **Release preload** backs the load down to ~0 N (correct unloading direction) → re-preload works.
- **Result:** PASS — releases to ≤5 N; safety halt if load rises; cancel via button / manual dir / E-Stop.

## 3. Auto-stop at fracture  ✅ CONFIRMED 2026-07-28 (S16, via Fracture test button)
- [x] **Fracture test** on **S16** (100 % infill) → fractured; load collapsed **2992 → −417 N** and the motor stopped at the collapse.
- **Result:** PASS — auto-stop caught the fracture. UTS **47.4 MPa** (anchor-corrected, V6-consistent); registry `S16`. First successful post-stall-guard fracture.

## (feature) Stall guard  ✅ VALIDATED 2026-07-28 (S16)
- [x] During S16's ductile drawing (force 3374 → 3070 N while the crosshead kept advancing 5.1 → 7.8 mm) the guard correctly did **NOT** trip — the near-zero-only 6 s threshold is confirmed. (S15 stall = the failure case it's built for; see TEST_FAILURES.md.)

## (feature) Fracture test button  ✅ VALIDATED 2026-07-28 (S16) — checklist → auto-pull → auto-stop at fracture worked end-to-end.

## 4. Settings (dropdown + Load / Save…)  ✅ CONFIRMED 2026-07-27
- [x] Set inputs → **Save…** with a name → appears in the dropdown; the JSON captures the values.
- [x] Select a saved profile → **Load** → inputs (area/gauge/preload/speed/DIC mode/infill/auto-stop) restore.
- [x] **Default** present + pre-selected on startup.
- **Result:** PASS — "Test 0" saved preload 300 N / speed 0.2 mm/s and Load restored them. NOTE: selecting only browses; **Load** applies.

## 5. Generate report (button)  ✅ CONFIRMED 2026-07-28 (S16)
- [x] Report generated for S16 → one-page PDF + PNGs.
- [x] Every value verified against the CSV/analysis (UTS 47.4 / σ_y 47.0 / E 1.88 / ε_f 6.0 / anchor 418), settings + validation + plots all faithful. DIC-health header line present.
- **Result:** PASS — report is a faithful render of the CSV (raw header Max Stress 42.18 = anchor-corrected report UTS 47.4).

## 6. Strain-rate mode (BETA)  ⚠️ live motor control — scrap specimen first
### 6.1 — dead-DIC guard (do FIRST)
- [x] **S17, 2026-07-28:** covered a marker mid-run → guard FIRED ("DIC strain frozen — halted for safety"), no fracture (15.9 MPa). Guard *detection* ~1.5 s ✓.
- ⚠️ **Flaw exposed:** while blind, the controller RAMPED UP (0.2 → 0.4 mm/s cap) chasing the frozen strain → force spiked **753 → 1271 N**, total halt **2.94 s**, +0.63 mm.
- ✅ **FIX applied (main.py):** stale strain now **FREEZES speed at 0.5 s** (no blind ramp-up) + dead-DIC halt tightened **1.5 → 1.0 s** (`POLICY_STALE_FREEZE_S` / `POLICY_DEAD_DIC_S`).
- [x] **RE-TEST (T2/T3, fix on):** overshoot cut — T2 peak **0.22 mm/s / +175 N** (clean, no ramp); T3 0.36 mm/s / +407 N (partial ramp at high load) vs T1's 0.40 mm/s / +518 N. Both halted. Freeze then **tightened 0.5 → 0.2 s** to kill the residual pre-freeze ramp. **PASS.**
### 6.2 — strain-rate to fracture  ✅ PASS 2026-07-29 (50% infill)
- [x] **50% specimen (fractures ~1.4 kN, under today's ~2.6 kN torque ceiling):** strain-rate held **0.00051 /s vs 0.0005 target** while the crosshead speed **auto-adapted 0.10 → 0.05 mm/s** (fast in stiff elastic, slow in necking) — true constant-*gauge*-strain-rate control, not constant crosshead speed. **Fractured** (UTS 1387 N / 17.3 MPa nominal, 20.5 MPa anchor-corr, anchor 255 N) and **auto-stopped on load collapse**. Speed ≤ 0.2 cap, no stall.
- NOTE: the 100% attempts (S17/fresh) could NOT fracture — motor's variable **torque ceiling ~2.6 kN today** (see `project_motor_stall_limit`), NOT a strain-rate issue (a normal S15 pull also stalled ~2.6). Infill label left at 100% in the CSV header (cosmetic; set Infill=50 next time).

## 7. Advanced test modes — cyclic · staircase · relaxation · creep  (wired 2026-08-08)
UI: "Advanced test modes (BETA)" segment in Motor Control — enable checkbox (greys the whole
segment until ticked) → Test-type dropdown + per-mode settings + **?** help diagram → Start test.
Shares `_policy_step` with strain-rate; `_policy_step` extended to drive **tension / compression /
hold**, with **phase-aware guards** (stall guard silent during an intentional hold; dead-DIC guard
only for DIC-steered modes) + adaptive timeout (hold duration + 300 s).
All runs below on **scrap specimen #1** (100 % infill), 300 N preload → Prepare → run.

### Session 1 — holds  ✅ PASS 2026-08-08
- [x] **T1 Creep** (400 N / 60 s / 0.1): ramped, entered hold, parked **~395–403 N** with position frozen at 0.6135 mm for ~80 s; small compression nudges worked; clean "creep complete".
  - ⚠️ **Overshoot 400 → 448 N (+12 %)** on arrival = the ~1 s decel coast. **FIX:** `CreepPolicy.ease_frac` (taper the last 25 % of the approach). Sim on a T1-calibrated plant: **38.8 N → 0.6 N**.
- [x] **T2 Relaxation** (ε 0.010 / 60 s / 0.1): stopped ramping at ε 0.010 = **2145.9 N (26.8 MPa)**, held position 2.8252 mm, **force decayed 2145 → 2040 N (~5 %)** at flat strain — textbook stress relaxation. DIC 99 %.
  - NOTE: ε targets are **heavy** on stiff 100 % infill (E≈2.68 GPa → ~215 N per 0.001 strain). ε 0.010 ≈ 2.45 kN absolute, near the ~2.6 kN ceiling. Use **ε 0.003–0.005** for a gentle elastic relaxation.
- ✅ **Stall guard stayed silent through both holds** (crosshead frozen, load ≫ 200 N) — phase-aware fix validated on hardware.

### Session 2 — staircase, Linear vs Smooth  ✅ PASS 2026-08-08
Same specimen + identical settings (300 N start / 300 N step / 3 levels / 20 s dwell / 0.1), only the ramp shape differs.

| Level | T3 **Linear** peak | over | T4 **Smooth** peak | over |
|---|---|---|---|---|
| 300 N | 345.5 N | **+45.5 (15.2 %)** | 306.0 N | **+6.0 (2.0 %)** |
| 600 N | 646.8 N | **+46.8 (7.8 %)** | 604.8 N | **+4.8 (0.8 %)** |
| 900 N | 952.6 N | **+52.6 (5.8 %)** | 907.8 N | **+7.8 (0.9 %)** |

- [x] 3 levels hit in order; **dwells 20.3/20.2/20.0 s (T3), 20.4/20.5/20.0 s (T4)** — spot on.
- [x] **Stall guard silent through all 6 dwells** (20 s frozen at 300–950 N).
- [x] Sine speed profile visible in T4: **0.01 → 0.096 → 0.0025 mm/s** per ramp.
- [x] Bonus real data — **stress relaxation at every level**: T3 −4.4/−2.9/−2.4 %, T4 −3.9/−2.9/−2.1 %.
- ⚠️ Smooth **doubled ramp time** (25.3 s vs 12.7 s) because `sin(π·frac)` also eased the ramp *start*, which buys no accuracy. **FIX:** taper only the top `ease_frac` (matches creep). Sim on a T3/T4-calibrated plant (850 N/mm, 1.24 s decel): overshoot stays ≤1 N, ramp **27.0 s → 18.0 s** (linear 11.2 s).
- **Verdict:** Smooth is the better default — ~85–90 % less overshoot for ~60 % more ramp time.

### Session 3 — cyclic  ✅ PASS 2026-08-09 (specimen S20, 100 % infill, folder `8.7/`)
Low 100 / High 500 N / **5 cycles** / 0.1 mm/s, 300 N preload → Prepare. Both runs: **5 cycles, 10 reversals, no stall, clean finish.**

| | peaks (target 500 N) | troughs (target 100 N) |
|---|---|---|
| **T5 Triangle** | 556/566/573/574/588 → **+71.5 N** | 24/34/24/24 → **−73.6 N** |
| **T6 Sine** | 502/506/513/512/507 → **+7.9 N** | 78/79/79/74 → **−22.7 N** |

- Triangle really cycled ~26↔572 N; Sine ~78↔508 N. **Sine 9× tighter at the top, 3× at the bottom.**
- ⚠️ **Asymmetric turnaround:** unload→load takes **~2.0 s** vs **~1.3 s** load→unload, in both waveforms — that is why the low bound is always the worse one.
- **Stiffness stable** all 5 cycles (1204/1273/1212/1251/1246 N/mm) → no fatigue damage. Cycle 1 reads 760–780 N/mm = slack take-up (same engaged-regime effect as V4b/V4c).
- **Hysteresis ≈ 19–21 mJ/cycle** steady (includes rig friction → upper bound on material damping).
- **Shakedown** visible in T6: peak-position drift 0.027 → 0.012 → 0.005 → 0.001 mm.
- 🆕 **Dynamic modulus:** DIC resolved the small-amplitude strain on 8 strokes → **E_cyclic = 3.7–3.8 GPa** vs monotonic secant **2.60 GPa** (≈1.45×, classic unrelaxed > relaxed for a viscoelastic polymer). Stroke 1 (2.2 GPa) is slack-contaminated; ±8 % from ~1.3 px of travel.
- Sine's predicted ~16 s start crawl was real; durations 67 s (T5) vs 127 s (T6).
- Stall guard did **not** false-trip on the sine's low-speed zones.

### T6.2 — cyclic Sine RE-RUN  ✅ RAN 2026-08-09 (mixed: low bound fixed, high bound worse, flat bottoms)
T6 showed a **stepped, non-sinusoidal** wave and loose bounds. Three fixes landed (`control_policies.py`, and the deadband in `main.py`) — **T6.2 is the rig check**:
1. SetSpeed deadband **0.01 → 0.002 mm/s** for waveform modes (sine was quantised to only ~10 velocity steps — the visible faceting).
2. Velocity law `sin(pi*frac)` → **`2*sqrt(frac(1-frac))`** = a true sine in time (old law ~2× too slow near the bounds).
3. **Adaptive predictive reversal** — reverses early by `rate x decel`, with `decel` self-tuned per direction from the observed violation. Seeded at zero lead + gain 0.7 so it converges from below (seeding it high made cycles 1–3 reverse far too early; full gain rang).
- Sim (T5/T6-calibrated plant): settled bound error sine **3.2 → 1.2 N** high, **21.7 → 10.1 N** low; cycle time 17.0 → 12.1 s. Shape only 10.8 → 9.7 % RMS — the residual is the *mechanical* reversal, not the law.
- [x] **T6.2** — RAN 2026-08-09 (S20). 5 cycles, no stall. **Mixed: low bound fixed, high bound worse, and flat bottoms appeared.**

| | T6 | T6.2 |
|---|---|---|
| high bound | +7.9 N | **+15.6 N** ❌ not converging (511/520/512/516/519) |
| low bound | −19.2 N | **−2.8 N** ✅ converging (−39.6 → −19.8 → +9.9 → +2.6) |
| duration | 127 s | **95 s** ✅ |

  - ❌ **Flat bottoms** (visible in the plot as a long dwell between humps). Root cause found: the sine law clamped `frac` to the nominal bounds, so **below f_low it returned 0 and the 0.01 mm/s floor took over**. Every reversal undershoots past f_low, so every cycle fell into that dead zone. Proof from the CSV: commanded **0.0159 mm/s below the bound vs 0.0635 above**, and climb-out **10.4 / 10.6 s** for troughs that dipped below vs **5.8 / 6.4 s** for troughs that stayed above.
  - ❌ **High bound could not converge** — the lead was scaled by the load rate, but with a sine the rate → 0 *exactly at* the bound, so the lead vanished right when needed. Structural; no amount of adapted decel fixes it.
  - ❌ Run ended at a **133 N** trough because the low-side lead had grown that large and tripped the cycle-complete test early.

### T6.3 — cyclic Sine RE-RUN #2  ✅ PASS 2026-08-09 (both bounds converge, dead zone gone)
1. **Waveform shaped over the ACHIEVED extremes** (`_lo_seen`/`_hi_seen` + 5 % margin) instead of the nominal bounds → **no dead zone, no flat bottoms**; floor raised 0.01 → 0.02 mm/s.
2. **Lead adapted in FORCE units, not rate×time** — we backed off by `lead_used` and still ran `over` past the bound, so the true coast is `lead_used + over` = the next lead. Rate-independent → converges for any waveform. Gain 0.85. Final trough stops at the true bound with no lead.
- Sim (5 cycles): sine peaks **518/522/512/502/493**, troughs **71/56/66/87** (vs no-lead 518/528/534/533/535 and 71/48/34/28); crawl-at-floor **1.8 s**; **55 s** vs T6.2's measured 82 s.
- [x] **T6.3 — PASS 2026-08-09.** Both bounds now CONVERGE onto target, and the flat bottoms are gone.

| cycle | 1 | 2 | 3 | 4 | 5 |
|---|---|---|---|---|---|
| peaks (target 500) | 528.0 | 529.2 | 515.6 | 505.1 | **499.6 (−0.4)** |
| troughs (target 100) | 50.5 | 75.3 | 94.3 | **100.3 (+0.3)** | 74.0 (final Stop, no lead) |

  - **Dead zone eliminated** — climb-out from a *below-Low* trough: T6.2 **10.4 / 10.6 s** → T6.3 **7.1 / 5.6 / 5.3 s**. Commanded speed below the bound **0.0159 → 0.0281 mm/s**. T6.3 climbs out of a 94 N trough in 5.3 s where T6.2 needed 5.8 s starting from 110 N (already *above* the bound).
  - **Duration 127 s (T6) → 95 s (T6.2) → 65 s (T6.3).**
  - ⚠️ Don't read the "mean bound error" — it averages cycle 1's deliberate transient with cycle 5's near-zero. The lead seeds at 0 and grows by design; judge the **trend**.
  - Leftover (cosmetic): the final trough lands at 74 N (−26) because the last trough uses no lead and the Stop still coasts. Traded T6.2's +33 for −26. Half-lead on the final trough would split it.
- [x] **Release load** — renamed, drives past tared 0 to −(tared-away load) = true zero. Safety floor made relative. Speed **0.30 → 0.20 mm/s** (0.30 felt too fast on the rig).

---

## 8. Fracture protocols (destructive) — T7 ✅ / T7.2 ✅ PASS / T8 ✅ PASS

**Specimen map (2026-08-09 session).** `S20` = **100 %** infill, carried every non-destructive mode
(creep · relaxation · staircase Linear/Smooth · cyclic Triangle/Sine) and then **T7**, where the motor
stalled — specimen survived intact. `S18` = **50 %** infill → **T7.2** (staircase→fracture).
`S21` = **50 %** infill → **T8** (progressive-cyclic→fracture). T7.2 and T8 are therefore **different
specimens**, which matters for how the cross-protocol agreement below is read.

The plain **Fracture test** button = a **monotonic (quasi-static) uniaxial tensile test to failure** (ASTM D638 / ISO 527): one continuous pull to load collapse → one E, one σ_y, one UTS. T7/T8 reach the same fracture but interrogate the specimen on the way, so **one specimen yields a curve instead of a point**. Both are in the advanced-mode dropdown behind a destructive-test confirmation.

**Motor note:** measured peaks in `8.6.20/` are **S16 3374.6 · V6a 3350.7 · V6c 3275.0 · V6d 3218.4 · V6e 3162.2 · V6b 3109.7 N** — six 100 % infill specimens over 3.1 kN, all fractured. Normal ceiling **3.2–3.4 kN**; the ~2.6 kN figure is a *thermally derated* session, NOT a hard limit. 100 % infill at the full 80 mm² fractures fine.

### Common to both
1. Mount specimen → preload **300 N** → **Prepare specimen** (now clears BOTH plots).
2. Tick **Advanced test modes**, pick the type, set params, **Start test** → confirm the destructive dialog.
3. At the end the console prints a **summary table** (per level / per cycle).
4. ⏸️ **Let the motor cool between T7 and T8** — back-to-back high-force runs are what produced the derated ~2.6 kN sessions.
5. A stall-guard trip is a *motor* result, not a protocol failure.

### T7 — Staircase → FRACTURE
| param | 100 % infill | 50 % infill |
|---|---|---|
| Start | **400 N** | 200 N |
| Step | **300 N** | 150 N |
| Dwell | **10 s** | 10 s |
| Speed | **0.100 mm/s** | 0.100 |
| Ramp | **Smooth** | Smooth |

~11 levels, **≈4–5 min**. Save as `_T7_StaircaseFracture`.
- **Dwell = 10 s is sufficient** (measured): 10 s captured **77 % / 67 %** of the full ~18 s drop in the T3 dwells. Enough for *yield detection*, where only consistency between levels matters and the 6–12 N drop is ~5× load-cell noise. NOT enough for quantitative viscoelastic work — use the dedicated Relaxation mode for that (10 s = only 41 % of an 81 s hold).
- **Keep Ramp = Smooth.** In Linear T3 the drop was 11.7 N at 345 N but only 6.3 N at 937 N — backwards for true relaxation. That is the 45–53 N arrival overshoot decaying during the dwell and masquerading as relaxation; Smooth cuts overshoot to 5–8 N.
- **Watch:** the `relax-drop` column — small and roughly linear while elastic, then an **abrupt jump** once a level passes yield. That is the yield-onset signature this protocol exists for.
- If late levels **crawl**, that's expected (the Smooth taper is calibrated for elastic stiffness; the specimen is far softer past yield) → switch to **Linear**.

### T8 — Progressive cyclic → FRACTURE
| param | 100 % infill | 50 % infill |
|---|---|---|
| 1st peak | **600 N** | 300 N |
| Peak step | **300 N** | 150 N |
| Unload to | **150 N** | 100 N |
| Speed | **0.100 mm/s** | 0.100 |

~10 cycles, **≈5–7 min**. Save as `_T8_ProgressiveCyclic`.
- 🔴 **Primary risk to watch:** if it stops after **cycle 1 or 2** announcing FRACTURE, the per-rising-stroke collapse watch has false-fired on the *intentional* unload — the exact failure mode this design guards against (armed only past halfway to the current target). **Stop, send the CSV, do not retry.**
- **Watch:** `unload-K` per cycle (stiffness degradation `D = 1 − Eᵢ/E₀`) and the rising trough position (permanent set).

**Sim status (elastic-plastic plant: yield 2900, break 3300, K 1210):** T7 fractures level 9 @222 s, relax-drop grows 2.8 → 26.0 N; T8 fractures cycle 8 @peak 3300 N after 7 clean cycles, peaks within ~5 N of target, trough position jumps 0.40 → 0.65 mm at yield. Three policy bugs already found and fixed by that sim (`self.step` shadowing `step()`; logged peak was the trigger not the true post-coast peak; fracture record mutated + duplicated the last row).

### T8 RESULT — ✅ PASS 2026-08-09 (specimen **S21**, 50 % infill, 300 N preload, step 150 N, unload 100 N, 0.100 mm/s)

**8 clean cycles, then fracture on rising stroke 9** (target 1500 N never reached; peak 1396.8 N).
**No cycle-1/2 false-fire** — the per-rising-stroke collapse watch (armed only past halfway to target)
held through all 8 intentional unloads, which was the one real design risk in this mode.

| cy | peak N | target | err | E_unload | dissipated |
|---|---|---|---|---|---|
| 1 | 333.0 | 300 | **+33.0** | — | 31.7 % |
| 2 | 455.2 | 450 | +5.2 | — | 12.4 % |
| 3 | 595.2 | 600 | −4.8 | — | 10.8 % |
| 4 | 755.7 | 750 | +5.7 | 2.32 GPa | 11.4 % |
| 5 | 893.4 | 900 | −6.6 | 2.12 GPa | **9.6 % (min)** |
| 6 | 1046.0 | 1050 | −4.0 | 1.97 GPa | 15.2 % |
| 7 | 1197.5 | 1200 | −2.5 | 1.85 GPa | 19.6 % |
| 8 | 1338.0 | 1350 | −12.0 | 1.73 GPa | **29.6 %** |

- **Peak tracking:** cycle 1 overshoots **+33 N** because the adaptive reversal lead is seeded at 0 and
  converges *from below* (deliberate — seeding at the measured decel time over-led and rang, see T6).
  From cycle 2 on, |err| ≤ 12 N (mean 5.8 N) = 0.4–1.3 % of target. Troughs held 97.9–116.4 N vs 100 N.
- **Damage curve (the science):** unload modulus from **DIC** strain falls **2.32 → 1.73 GPa over cycles
  4→8 = 25 % stiffness loss**, monotonic. Robust to the fit window (top-55 % vs top-30 % of the unload
  both give 21–26 %). Hysteresis dissipation bottoms at **9.6 % (cycle 5)** then accelerates to 29.6 %.
  Residual DIC strain per-cycle increment jumps 5× at cycle 8 (+0.00163 vs ~0.0003 typical).
- ⚠️ **Cycles 1–3 unusable for modulus** (R² 0.17–0.82, cycle 1 even negative): the DIC strain *change*
  during those small unloads is below the noise floor. The metric only becomes trustworthy once the peak
  exceeds ~750 N. Dissipation (an energy integral over a large position range) does NOT have this
  problem and is the better damage metric on this rig.
- 🔴 **Crosshead stiffness trends the WRONG WAY:** 613 → 777 N/mm, *increasing* monotonically as rig slack
  is squeezed out, while the specimen is genuinely softening. **Without DIC this test would have concluded
  the specimen was stiffening.** Strongest single argument for the DIC channel yet — put it in the deck.
- **Fracture:** peak 1396.8 N nominal (17.46 MPa) at t=262.8 s, ~9 s of plateau/necking, collapse at
  t=272.0 s (961 N in one sample). Detector correctly stayed silent through the plateau.
  **Auto-halt 1.33 s** after collapse (T7.2 was 1.09 s).
- **Anchor 313.2 N** (tail sd 0.22 N) → **true UTS 21.38 MPa**.
- ✅ **Cross-protocol agreement — 0.9 %:** T7.2 (staircase, **S18**) gave **21.19 MPa** (anchor 307.4 N);
  T8 (progressive cyclic, **S21**) gave **21.38 MPa** (anchor 313.2 N).
  ⚠️ **These are two different specimens**, so the 0.9 % spans *both* the protocol difference *and*
  specimen-to-specimen scatter — the two cannot be separated from n=2. Read it as "protocol choice does
  not shift UTS by more than the specimen scatter, and that combined spread is ≤1 %", which is the useful
  claim and is stronger than a same-specimen repeat would be. A true protocol-only comparison would need
  both protocols on specimens from one print batch, n≥3 each.
  Yield onset is bracketed **700–900 N tared (≈12.6–15.1 MPa true)** by T7.2's relaxation-drop knee and
  T8's dissipation minimum — different physics, so a bracket rather than a single value.
- **Recipe feature's first real use** — "T8 Progressive cyclic 50%" loaded the mode + all 4 params correctly.

- **After T7/T8:** build the deck slides for all the control modes + fracture protocols.

---

## Rig facts to report back (these unblock the remaining test modes)
- [x] **Hold on STOP** — CONFIRMED 2026-07-27: after Stop, δ held at −1.9191 mm across 5/10/15 s (zero drift). Motor has holding torque → staircase / relaxation *dwell* works via Stop. (SetSpeed-0-specific hold not separately tested — not required.)
- [x] **Reversal** — CONFIRMED 2026-07-28 (video frame analysis): a DIRECT opposite-direction click auto-reverses cleanly — smooth decel → ~1 s stop (δ holds, no overshoot/jolt) → accel in the new direction. No manual Stop needed. Cyclic/creep can issue direct direction changes; velocity readout is signed (+ Down / − Up).
- [x] **Travel cap → 30 mm** (2026-07-28): lowered from 45 mm by visual inspection (45 looked too much). Counts from the tared zero; ~2x a PLA fracture test's ~8-15 mm. Optional: jog top→bottom to confirm physical stroke ≥ 30 mm.

## Known limitation logged (2026-07)
Multi-marker Poisson / true Cauchy from transverse dots is **not feasible** on the current
mini-dogbone: the gauge is too narrow for a transverse pair, and at ~20 px/mm the elastic width
change is sub-pixel. Path chosen instead: **analytical Cauchy stress** from measured axial strain
+ assumed ν≈0.35 for PLA, A = A₀(1 − ν·ε)². Real measured Poisson would need a gauge-zoomed camera
(higher px/mm) + dark backdrop, or a dedicated extensometer.

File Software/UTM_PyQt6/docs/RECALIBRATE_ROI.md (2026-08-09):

# Recalibrate ROI — Playbook

Use this when `camera_setup.py` reports **0 blobs** (or shows blobs near the ROI edge) after you move the camera or specimen. The workflow transforms the new dot positions into a pylon ROI.

---

## When to do this

- `camera_setup.py` verdict = FAIL with "0 blobs in most frames"
- Blob edge margin < 30 px (camera drift will clip)
- Any bench setup change: camera mount, lens, specimen swap, lighting

---

## Step-by-step

### 1. Capture the full sensor

```
python grab_full_frame.py
```

Output: `setup_output/full_frame.png` — shows the whole 2448×2048 sensor (post-rotation 2048×2448).

### 2. Overlay a coordinate grid

```
python grid_full_frame.py
```

Output: `setup_output/full_frame_grid.png` — red grid at 100 px spacing with axis labels.

### 3. Read the dot centers off the grid

From the gridded image, note the **center pixel** of each dot in **post-rotation** coordinates:

```
Top dot    : (x_post_top,    y_post_top)
Bottom dot : (x_post_bottom, y_post_bottom)
```

Typical values have `y_post_top` small (near 0) and `y_post_bottom` larger (~1500).

### 4. Transform to pre-rotation (pylon) coordinates

Pylon applies the ROI **before** rotation, so we transform the post-rotation clicks back:

```
x_pre = y_post
y_pre = 2047 − x_post
```

(Constant 2047 = `sensor_height − 1` for the 2448×2048 sensor.)

You now have two points in pre-rotation space:

```
Top dot    : (x_pre_top,    y_pre_top)    ≈ small y_post  → small x_pre,  y_pre near 2047 − x_post_top
Bottom dot : (x_pre_bot,    y_pre_bot)
```

### 5. Build the ROI

The ROI is a rectangle in pre-rotation coordinates: `[OffsetX, OffsetY, Width, Height]`.

```
x_pre range covered: [OffsetX,           OffsetX + Width]
y_pre range covered: [OffsetY,           OffsetY + Height]
```

Pick values that enclose **both dots** with at least **~40 px margin** around each dot (dots are ~80 px diameter, so margin from dot edge matters).

**Basler rounding rules** (required, or pylon will reject):
| Parameter | Must be multiple of |
|---|---|
| OffsetX | 4 |
| Width | 4 |
| OffsetY | 16 |
| Height  | 16 |

**Sensor limits:**
- `OffsetX + Width  ≤ 2448`
- `OffsetY + Height ≤ 2048`

### 6. Edit `camera_manager.py`

Two places must stay in sync:

**Line ~36 (class default):**
```python
ROI = [OffsetX, OffsetY, Width, Height]
```

**Line ~57 (Black preset) or line ~47 (White preset):**
```python
"roi": [OffsetX, OffsetY, Width, Height],
```

### 7. Verify

```
python camera_setup.py --mode black
```

Expect:
- Detection rate ≥ 95 %
- Distance std dev < 0.5 px
- Edge margin ≥ 30 px on both blobs

If PASS → you're ready to tare and run.

---

## Worked example (2026-04-22)

Grid reading:
- Top dot post    = (895, 50)
- Bottom dot post = (820, 1490)

Transform:
- Top dot pre    = (50,   2047 − 895)  = (50,   1152)
- Bottom dot pre = (1490, 2047 − 820)  = (1490, 1227)

Envelope with margin:
- x_pre : [0, 1700]     → OffsetX=0, Width=1700 (both ÷4 ✓)
- y_pre : [1072, 1328]  → OffsetY=1072 (÷16 ✓), Height=256 (÷16 ✓)

Final: `ROI = [0, 1072, 1700, 256]`

---

## Quick reference — the whole chain in one shell session

```
python grab_full_frame.py
python grid_full_frame.py
# --- read dot centers from setup_output/full_frame_grid.png ---
# --- compute new ROI using the transform above ---
# --- edit camera_manager.py (2 places) ---
python camera_setup.py --mode black
```

---

## Tips

- **Pick the preset first.** White specimen (dark dots) → `--mode white`. Dark specimen (light dots) → `--mode black`. The preset controls threshold polarity and minimum circularity.
- **Bigger margin is cheap.** Going from `Height=208` to `Height=256` costs ~25 % more pixels per frame but gives you 48 px extra vertical drift tolerance.
- **Don't chase tight margins** unless you need max frame rate. Wider ROI = more forgiving to small camera jiggles.
- **History matters**: note the old ROI in a comment before editing, so you can roll back if needed.

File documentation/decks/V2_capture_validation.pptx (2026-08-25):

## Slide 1

Frame capture, validated on a real fracture test

One 100 %-infill pull to failure exercised five new features at once — and exposed one long-standing analysis error.

1 960

frames, each sink

0

dropped

99.95 %

DIC 2/2 markers

46.5 MPa

UTS — stands

17.5 %

ε_f — WRONG

CAPTURE PASSES. Stills, raw video and speckle video each wrote 1 960 frames over 98.3 s with not one dropped, while the DIC held both markers on 99.95 % of samples all the way to fracture.

THE REPORT'S FRACTURE STRAIN IS NOT A MATERIAL PROPERTY. ε_f = 17.5 % and toughness 6 774 kJ/m³ come from the broken halves springing apart after the specimen had already failed. The honest numbers are ε_f = 7.4 % and 2 992 kJ/m³. Strength and stiffness are unaffected.

Why this matters more than one specimen: every 8.6.20 fracture test analysed with the same detector carries the same error. ε_f and toughness are the two numbers integrated all the way to the chosen fracture index — so they are the two that move. UTS, σ_y and E are read at or before the peak and are untouched.

S24 · V2 · 100 % infill · spray markers · 2026-08-14 12:01 · 188.2 s · 2 135 samples

1

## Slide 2

Five features, one destructive specimen

The run was designed so a single pull would answer every open question from the last two days of software work.

1 960 lossless frames + index.csv, one row per file, 0 dropped

Frame capture — PNG stills

PASS

raw + adaptive-speckle written simultaneously, both readable end to end

Frame capture — dual AVI

PASS

load, DIC and plotting continued at full rate while 2.0 GB was written

GUI unaffected during capture

PASS

'# Capture:' header written; run.json names the CSV back

SF11 — CSV ↔ capture link

PASS

markers held to the last frame before fracture — 99.95 % at 2/2

Adaptive speckle under real LEDs

PASS

picked a post-fracture sample; ε_f and toughness both wrong

Fracture-point selection

FAIL

header stamped 35 fps, frames arrived at 19.9 — plays 1.76× fast

S24 · V2 · 100 % infill · spray markers · 2026-08-14 12:01 · 188.2 s · 2 135 samples

AVI playback rate

BUG

2

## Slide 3

The writer never fell behind

Every interval between consecutive frames, for the whole 98 s capture. A dropped frame is not a subtle effect — it doubles an interval, and there is no such interval here.

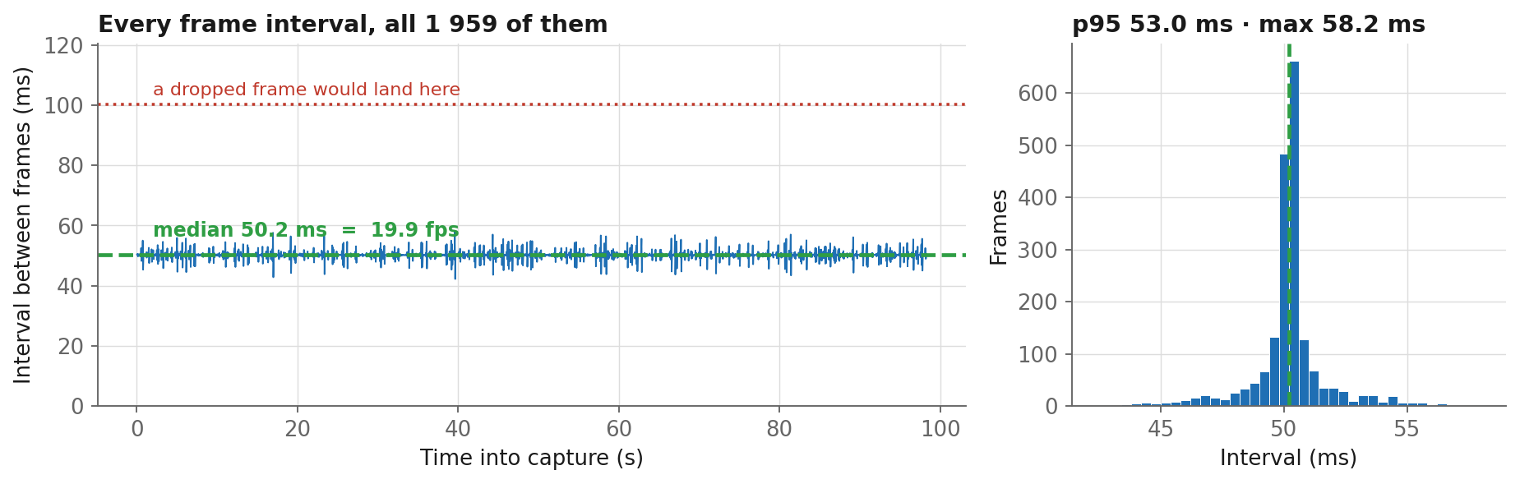
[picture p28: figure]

Median 50.2 ms · p95 53.0 ms · worst 58.2 ms. The slowest frame in the run was 16 % late, against the 100 % it would take to lose one.

This is the measurement that justified the design: cv2 releases the GIL while encoding, so the writer threads never contend with the GUI for the interpreter.

S24 · V2 · 100 % infill · spray markers · 2026-08-14 12:01 · 188.2 s · 2 135 samples

3

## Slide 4

Three sinks, one frame count

Stills and both video views were armed together. If any had lagged, its count would differ.

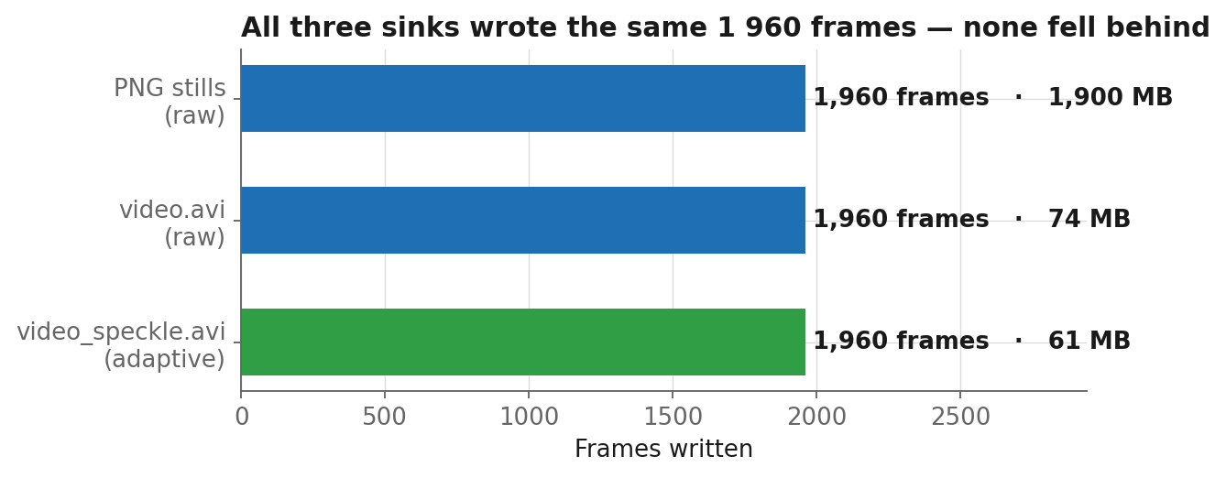
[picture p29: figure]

418 × 2348 px
MJPG, intra-frame
2.0 GB for a 98 s capture
— 1.24 GB/min, exactly what the setup dialog predicted
The 419→418 crop is the
odd-width MJPG rule: it crops,
never rescales, so marker
separation is preserved

ONE BUG. Both AVIs carry a 35 fps header — the camera's configured rate — but frames actually arrived at 19.9 fps. The files play 1.76× too fast, so anything timed off the video rather than off index.csv will be wrong. The frames themselves are correct.

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

4

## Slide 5

Writing 2.0 GB did not cost the rig a single sample

The requirement when this was specified was that capture must not slow the GUI, the data gathering rate or the plotting. The run measures it directly — same test, same specimen, capture on for the middle 98 s.

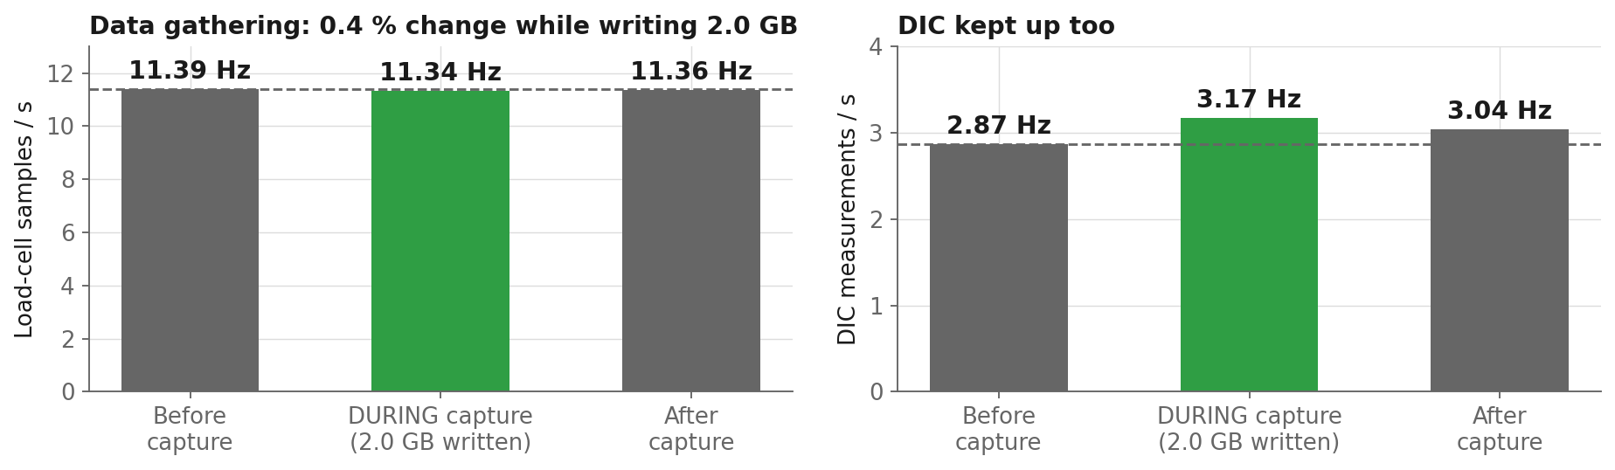
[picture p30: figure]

11.39 Hz before · 11.34 Hz during · 11.36 Hz after — a 0.4 % change, smaller than the variation between the two idle windows. The DIC ran slightly FASTER during capture, because that is the moving phase where markers are easiest to lock onto.

The design reason: OpenCV releases the GIL while encoding, so the PNG and MJPG writer threads genuinely run beside the Python GUI rather than taking turns with it.

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

5

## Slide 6

The DIC held both markers to the end

Adaptive speckle had only ever been proven against synthetic dimming. This is its first real test under the rig's own LEDs, on a specimen being pulled apart.

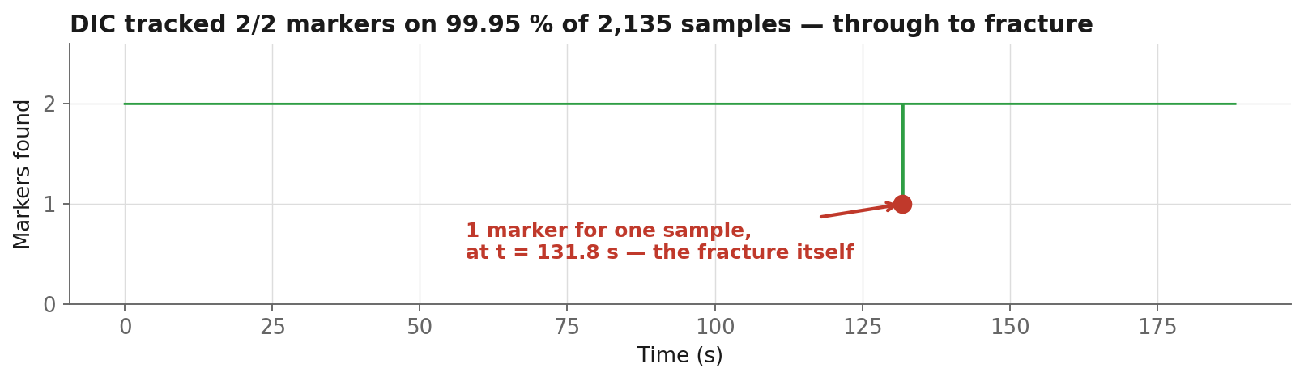
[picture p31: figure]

2 134 of 2 135 samples at 2/2 markers.
The single exception is one sample at t = 131.83 s — the fracture instant itself, when one half left the frame.

That one dropout is not a defect — it is the detector correctly reporting that the specimen stopped being one object. It is also the cleanest possible fracture timestamp, and the analysis should be using it.

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

6

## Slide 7

The finding: ε_f is measured after the specimen broke

The report places fracture at 17.5 % strain. The last sample at which the specimen was still in one piece is at 7.4 %.

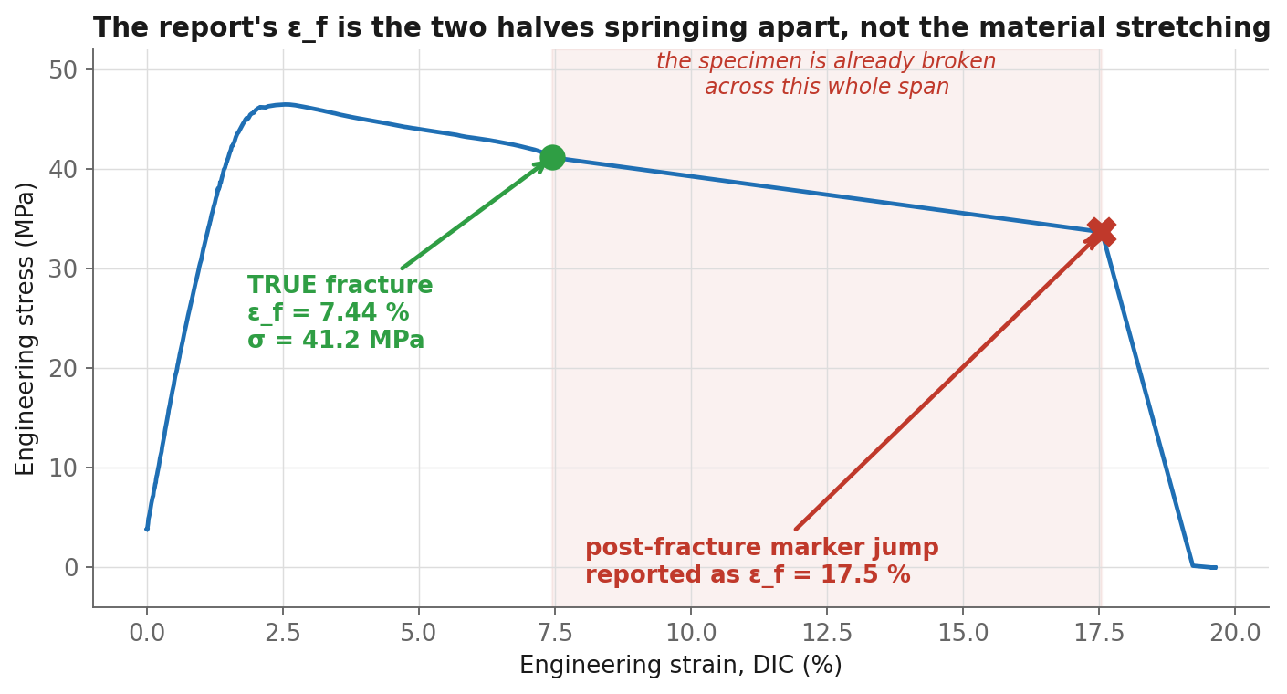
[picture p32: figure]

Between the green dot and the red X the load has already collapsed from 2 986 N to below zero. Nothing in that span is the material deforming — it is two separated halves and a relaxing frame.

ε_f 17.5 % → 7.4 %

toughness
6 774 → 2 992 kJ/m³

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

7

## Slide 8

What the markers actually did

Marker separation and load, either side of fracture. They break at the same instant, which is the whole argument.

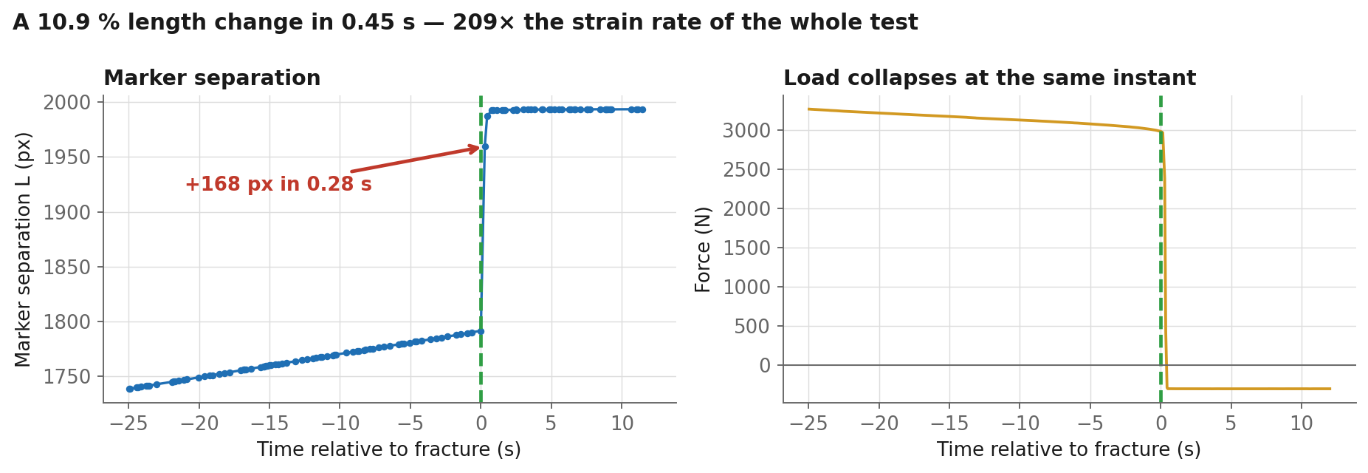
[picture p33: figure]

The gauge grew 196 px — 10.9 % — in 0.45 s. Through the preceding 90 s of pulling it grew at 1.26 × 10⁻³ /s. The jump implies 2.63 × 10⁻¹ /s: 209 times faster, at the exact moment the load fell to zero. PLA does not do that. A snapping specimen does.

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

8

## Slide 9

A check that needs no DIC at all

Strain is a ratio. Multiply it back into millimetres and compare against how far the machine actually moved.

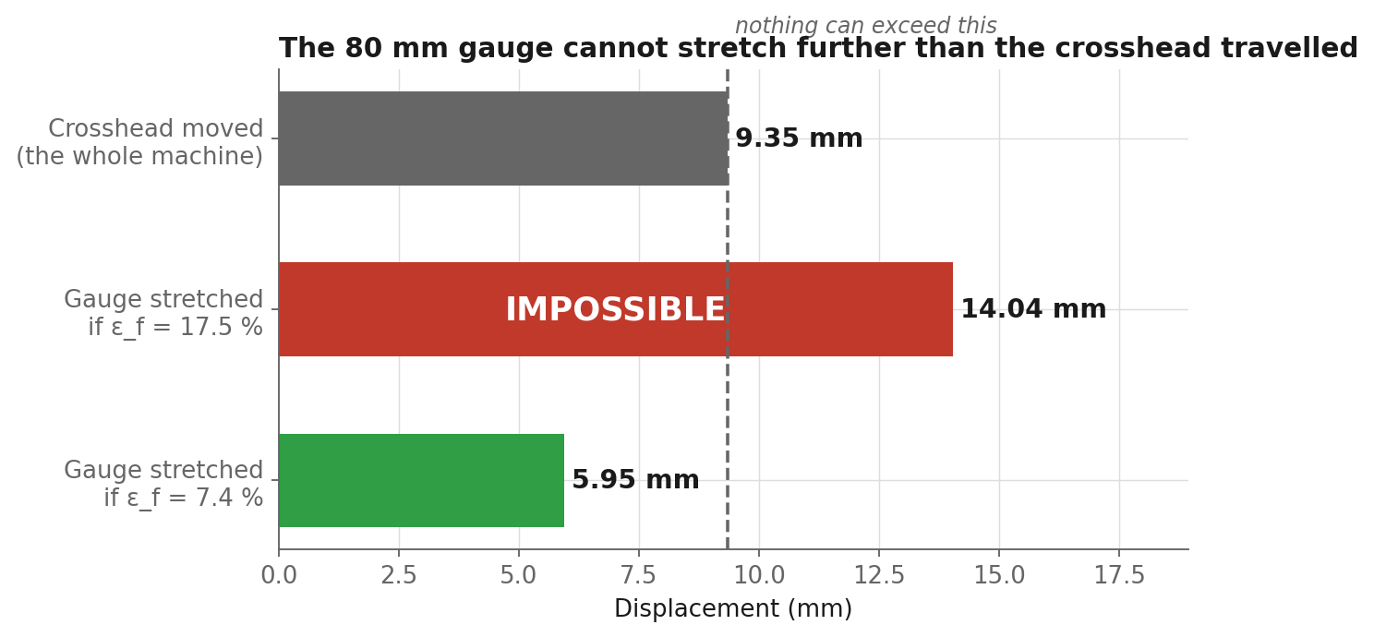
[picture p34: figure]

ε_f = 17.5 % on an 80 mm gauge means the gauge alone stretched 14.04 mm. The crosshead moved 9.35 mm in the entire test — grips, load train, frame and specimen combined. The gauge cannot out-stretch the machine, so 17.5 % is impossible on arithmetic alone.

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

9

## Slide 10

What changes, and what does not

Only the two quantities integrated all the way to the fracture index move.

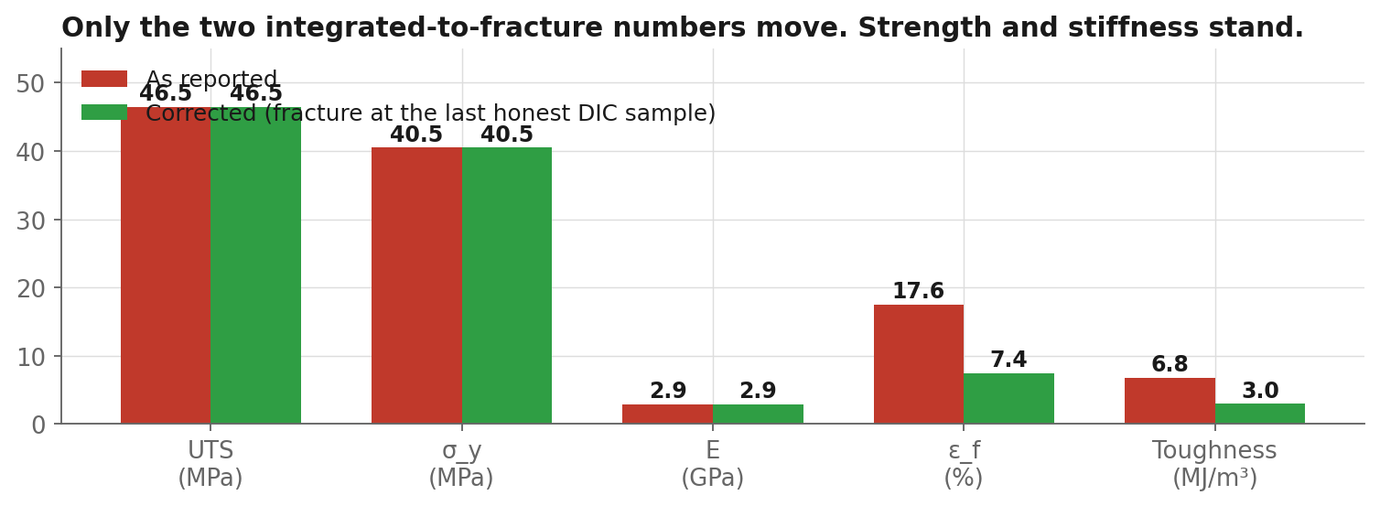
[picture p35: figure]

UNCHANGED — read at or before the peak
UTS 46.5 MPa · σ_y 40.5 MPa · E 2.93 GPa
Sits inside the V6 quintet (46.2 ± 1.2 MPa) and above its E of 2.60 GPa.

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

CORRECTED — integrated to fracture
ε_f 17.5 % → 7.44 %
toughness 6 774 → 2 992 kJ/m³ (2.26× overstated)
7.4 % also sits much closer to the 3–7 % of the V6 quintet.

10

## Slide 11

What to do about it

Three fixes, in the order they matter.

Take the fracture index from the load collapse, not the strain

The detector already finds the collapse — the load fell 1 957 N in one 80 ms sample. ε_f should be read at the last sample BEFORE it, not after. The DIC_Blobs column marks the same instant independently.

1

Re-run every 8.6.20 fracture test through the corrected detector

ε_f and toughness for the whole V5/V6 series were computed the same way. The V6 quintet's 3–7 % range suggests those were mostly fine — but 'mostly' is not a number you publish.

2

Stamp the achieved frame rate into the AVI, not the configured one

One line in the video writer. Until then, time anything off frames/index.csv, which carries a real PC timestamp per frame and is correct.

3

The capture feature itself needs no changes. It did exactly what it was built to do, on the first destructive test it was asked to survive.

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

11

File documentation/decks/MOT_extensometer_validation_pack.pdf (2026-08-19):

# PLA vs VIDEO EXTENSOMETER - MOT SESSION PACK

What to bring, what must match, and what we are comparing against

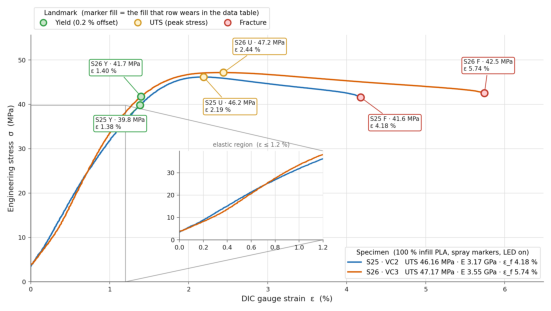
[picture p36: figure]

UTM DIC - PLA validation against a video extensometer - MOT session pack | 1

WHAT WE ARE VALIDATING. Our strain comes from two spray dots tracked in a Basler frame, 80 mm apart, at about 20.9 px/mm. Everything the campaign claims about PLA rests on that measurement being right. A video extensometer is an independent optical measurement of the same quantity, so agreement is the strongest evidence available without a contact extensometer.

WHAT WE BRING TO COMPARE. 11 fractured 100 % infill PLA specimens: UTS 46.58 +- 0.94 MPa (CV 2.0 %), E 3.02 +- 0.26 GPa (CV 8.5 %). Page 3 has the full table.

THE ONE THING THAT WILL COST YOU THE SESSION: THE STRAIN ZERO. Our Px0 is frozen AFTER a ~300 N preload, so our strain axis begins at an already-seated specimen. An extensometer zeroed at 0 N carries the toe - grip take-up and specimen straightening - inside its strain, which LOWERS apparent modulus and shifts the 0.2 % offset yield. That difference is bigger than the 8.5 %
scatter of our entire 11-specimen set. Match it, or agree in advance to
correct for it. Do not discover it in the data.

### CONTENTS

2 | Parameters that must match - the pre-flight
3 | Our reference values - the 100 % PLA set
4 | Comparison sheet - fill in at the bench
5 | Traps that make two correct instruments disagree
6 | What to physically bring
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

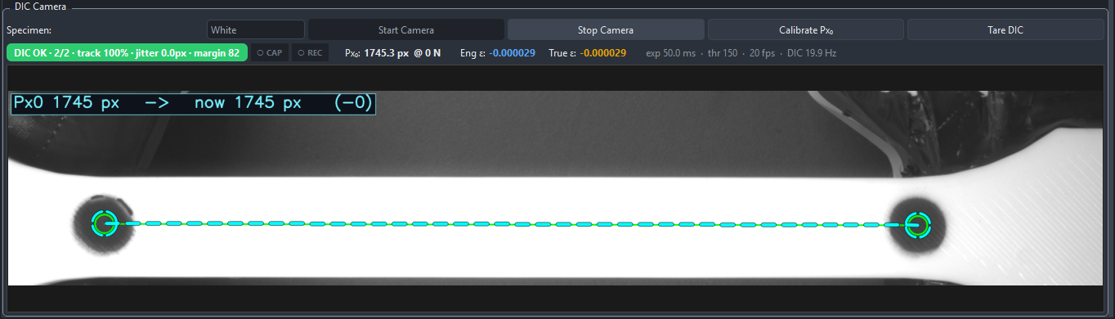
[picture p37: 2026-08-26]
images/features/CalibratePxo_live marker.png

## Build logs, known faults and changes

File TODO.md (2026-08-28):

# UTM — TODO

**App 0.5.4 · Firmware 1.3.1 · updated 2026-08-27**

Three documents, three jobs — do not merge them:

| doc | job |
|---|---|
| **this file** | what must happen next, in order. Deployment first, then open validation. **Software.** |
| **`MECHANICAL_TODO.md`** | the mechanical counterpart — alignment, compliance, backlash, load train. Development to date has been almost entirely software; this is the gap. |
| `Software/UTM_PyQt6/docs/ROADMAP.md` | living status of every feature (SF1–SF19) and the research campaign. **The detail lives there.** |
| `Software/UTM_PyQt6/docs/TEST_FAILURES.md` | runs that did not complete, with root cause. Read before blaming the software. |

---

## 🔴 P0 — Student deployment (guide ready Monday 2026-08-31; campaign runs 7 weeks)

~40 student groups generate tensile data over **seven weeks**, unsupervised for most of it. The app
is currently configured as a **research instrument for one expert operator**. Everything here is
about closing that gap and keeping it closed for seven weeks of forty different pairs of hands.

### Decisions to make before writing the guide

- [ ] **Resolve the Px₀ convention and write down the one you teach.** `README.md` states
      "Px₀ is frozen AFTER the preload"; SF18 added a **Calibrate Px₀** button explicitly so it
      could be frozen BEFORE preload, and the wizard warns on an unloaded Px₀. Both are defensible;
      an ambiguous procedure taught to 40 groups is not. Pick one, make the wizard agree, fix the
      README. **Blocks the guide.**
- [ ] **Mandate white markers, not black.** Black-mode runs show an unexplained DIC delivery
      collapse — S13 lost **51 %** of coverage, S29 **21 %**, while white S26 held **99.9 %**
      (ROADMAP §3a item 6, still open, n = 3). Do not put a seven-week campaign on the untriaged path.
- [ ] **Infill is a free variable — there is no force ceiling.** The "2.6 kN motor ceiling" was
      a mechanical misalignment, resolved 2026-08-12 (loose load holders + binding screws), and the
      rig is rated to **~15 kN**. 100 % infill has fractured 11 times at 3586–3826 N. Let the groups
      choose infill; just make them **log it**, since it is the most interesting variable they have.

### App changes (small, low risk, high leverage)

- [ ] **Ship a `Student` settings profile** in `utm_recipes.py` beside `Default` and `TPU`.
      The single biggest lever: one dropdown entry moves preload, speed, strain cap, auto-stop, ROI
      and material together. Adi's own note applies exactly — *"two set and one forgotten is a
      wasted specimen."* Seeded by `ensure_default()`, so it appears on first launch on any machine.
- [ ] **Default the Guided wizard ON** — `main.py:5221`, `_recall_bool("ui/wizard_open", False)`
      → `True`. Turned off at the expert operator's request; students are the opposite case. Pure
      VIEW, AST-checked to reach no control path, so there is no risk in this.
- [ ] **Decide the registry policy.** `registry.json` auto-appends on Save. Over 40 runs this either
      becomes a genuinely good class dataset or it pollutes the research register. Decide before
      week 1, not week 4.

### Surviving seven weeks — the items a one-day session would not need

- [ ] **Weekly mechanical check, and put it in writing.** Loose load holders letting the crossheads
      go out of alignment is **the** documented failure mode on this rig (S15), and mounting and
      unmounting 40 specimens is exactly what loosens them. Weekly: **check load-holder torque,
      crosshead alignment, and screw lubrication.** A stall is now a maintenance signal, not a
      software one — if the stall guard ever fires, this is the first thing to check.
- [ ] **DIC auto-calibration is SESSION-ONLY — decide how that is handled.** `utm_autocal.py`
      never writes back to the preset in `camera_manager.py`, so every restart returns to the
      hand-set exposure and threshold chosen once under one set of LEDs. Over seven weeks the
      lighting *will* drift, and the first symptom is a ruined test. Either persist the result to
      the `Student` profile, or make **Settings ▸ Auto-calibrate DIC…** a mandatory step in the
      student procedure rather than the optional wizard row it is now.
- [ ] **Load-cell calibration check at least once mid-campaign.** Seven weeks and 40 mountings is
      long enough for the two-point calibration to drift; a known reference weight takes minutes.
- [ ] **Consumables and spares.** Marker spray, specimen stock, and a spare ESP32 / USB cable.
      A dead cable in week 3 with no spare costs a week of slots.

### Guide (written + recorded)

- [ ] **Written guide** — one page the students actually follow at the rig. Must cover the three
      things that will otherwise generate 40 identical questions:
      **force reads negative** after tare-at-preload on an unloaded or fractured specimen;
      the preload is not optional; Px₀ has exactly one owner (see decision above).
- [ ] **Recorded walkthrough** — one full run end to end: mount → preload → Calibrate Px₀ →
      Prepare specimen → Fracture test → auto-stop → Save → Generate report.
- [ ] **A one-page WHAT-WENT-WRONG sheet** beside the machine. Over seven weeks you will not be
      there for most runs. Cover: stall guard fired → call the supervisor, do not re-run;
      DIC shows 0/2 markers → re-run auto-calibrate; specimen did not fracture; force negative.
- [ ] **Dry-run the guide yourself on one specimen before recording**, following only what is
      written. Anything you reach for that is not in the guide is a gap.

## 🟡 P1 — Open validation (needs rig time, does not block Monday)

### HIGH — Quantify machine compliance

**Only 19–29 % of crosshead travel reaches the gauge.** This is a *validation* item, not a
mechanical-repair one: until it is quantified, every crosshead-derived number carries an unknown
machine term, and `Motor_Strain` is unusable as anything but a rough sanity check.

The frame is 80×80 aluminium and effectively rigid at 3.8 kN, so it is not the source. The
**specimen form-holder is printed 100 % PLA**, and bulk stiffness does not account for the loss —
the dominant term is **local contact crushing**, which also explains the rising-stiffness toe region.

- [ ] **Bearing-stress calculation** — 3800 N divided by the actual bearing area at each PLA contact
      face. PLA yields at ~50–60 MPa, so below ~70 mm² the holder crushes plastically on every test
      and the machine drifts softer across the campaign. **No rig time, no disassembly** — the
      holder drawing and a calculator. Do this one first.
- [ ] **Rigid-dummy compliance curve** — steel bar of the same grip geometry, pulled the same way.
      Isolates *frame + drivetrain + holder + contact*, i.e. everything that is not the specimen.
      Gives a force-by-force correction curve for crosshead strain.
- [ ] **Holder-creep check** — a relaxation run against the rigid dummy. Any force decay with no
      specimen present is holder creep, and it contaminates the creep / relaxation / staircase-dwell
      results until it is bounded.

Full mechanical context in `MECHANICAL_TODO.md` §3.

### Carried over from Phase 8.6

75 of 83 items complete.

- [ ] **8.6.3** Known-displacement test — Motor vs DIC Cauchy strain on a real specimen.
- [ ] **8.6.4** Strain sign test — tension (+) / compression (−) under real loading.
- [ ] **8.6.15** Printed-marker calibration — tare on 50 mm dot spacing, swap to 55 mm,
      confirm DIC Cauchy ≈ 0.1000. Validates the DIC maths end-to-end, independent of the UTM.
- [ ] **8.6.17** Motor encoder accuracy — command 1 / 5 / 10 mm, compare to `Position_mm`.
      Validates the `Motor_Strain` denominator.
- [ ] **8.6.18** Multi-session tare consistency — reconnect the camera between sessions,
      verify `px_per_mm` holds.
- [ ] **8.6.19** Elastic modulus characterisation — 0.05 mm/s ramp to ~0.5 mm compression,
      hold 30 s, return. Pass: R² > 0.99, E within 1–4 GPa, hold drift < 5 %.
- [ ] **DIC↔load-cell match** — hardware-verify that stall rows carry unique DIC values.
- [ ] Remove the temporary 8.4.6 validation log from `main.py` once the above pass.

---

## Stall guard — redesign or retire

**Disabled by default 2026-08-28.** Operator switch in Motor Control. Full write-up in
`Software/UTM_PyQt6/docs/STALL_GUARD.md`.

The velocity guard was written 2026-06-22 while the rig stalled near 2.6 kN. That was a
**mechanical** fault — loose load holders, binding crossheads — found and fixed 2026-08-12
(`9061daf`: *"a fastener, not a purchase and not a code change"*). The guard outlived the
repair and now E-Stops healthy motion.

- [ ] **Compare against COMMANDED speed, not a fixed 0.5 RPM.** Expected RPM is known
      (`mm_s / 5 * 20 * 60`). The current constant is 0.00208 mm/s at the crosshead whatever
      was asked for, so any test below ~0.002 mm/s cannot run with the guard on.
- [ ] **Detect the DROP, not the level** — the operator's suggestion, and the right one. A
      stall is a collapse from a held speed; a ramp is a rise from zero. Sign and
      "has this move ever reached speed" separate them.
- [ ] **Arm only once the move has reached speed**, instead of a flat 1 s grace period that has
      no relation to `setRampLen(100)`.
- [ ] **Cross-check the second encoder** rather than trusting one sensor — see
      `MECHANICAL_TODO.md` §2. Two encoders disagreeing is a better stall signal, and it also
      catches the racking that caused the original fault.
- [ ] **Do not re-enable by default** until at least the first two are done.

---

## UI / UX — before the students arrive (highest value per hour)

The panel grew feature by feature and the grouping now reflects **build order, not operator order**.
The original author could not find the motor enable switch; 40 students will not do better.
Raised 2026-08-27. All of this is layout — no measurement path is touched.

### Safety — do this one first

- [x] **DONE 2026-08-27 — The Emergency STOP scrolled out of view.** Moved out of
      `motorControlGroup` into `verticalLayout_outer`, outside `mainScrollArea`. It was also the
      insertion anchor for four runtime-built sections (`indexOf(self.emergencyStopButton)`), so
      those were rewritten to explicit appends. Verified by constructing the real window offscreen:
      parent chain is now `centralwidget → MainWindow`, panel order unchanged.
      ⚠️ **Still to check visually:** it now spans the FULL WINDOW width, not just the control
      column. Probably correct for an E-STOP — confirm, or wrap it in an HBox with a left stretch.

<details><summary>original report</summary>

- **The Emergency STOP scrolls out of view.** `mainScrollArea` (`ui/utm_mainwindow.ui:37`) wraps
      the whole control panel, and the E-STOP sits at **line 1270 — with `positionGroup` (1278) and
      `incrementalMoveGroup` (1304) below it**. It is not even the last widget, so it can be
      scrolled off in either direction. **Pin it outside the scroll area**, docked to the bottom of
      the panel, always visible.

</details>

### Reorder to match the operator sequence

The wizard already encodes the right order. The panel should mirror it: connect → enable motors →
data streams → preload → prepare → run → save.

- [ ] **Motor Control moves above Speed Control.** You enable motors before you set a speed.
- [ ] **`Motors` → `Enable Motors`**, moved to the **first row of Motor Control**, above Direction.
- [ ] **Put every switch immediately next to its label.** `Enable Motors`, `Connection` and the three
      Data Streams toggles all sit at the far right of a wide row with a gap between, so label and
      state have to be paired across empty space. Label → control → stretch, not
      label → stretch → control.

### Split Motor Control — it currently holds four unrelated things

Preload, specimen preparation, the strain-rate test and Advanced test modes are all inside a group
called *Motor Control*. Proposed grouping:

| Group | Contents |
|---|---|
| **Connection** | scan / port / connect (unchanged) |
| **Motor Control** | **Enable Motors** · Direction · jog speed |
| **Data Streams** | load cell · position · velocity (unchanged) |
| **Specimen** | settings profile · infill % · preload · release to preload / fully · Prepare test |
| **Run Test** | auto-stop · Fracture test · strain-rate test · Advanced test modes |
| **Save & Report** | Comment · File ID · Save Data · Generate report |
| **Emergency STOP** | pinned, outside the scroll area |

- [ ] **Name the data group `Save & Report`**, not `Data`. Comment and File ID are *inputs to* those
      two actions — File ID goes into the filename, the comment into the CSV header — so the group
      is named for what you came to it to do. `Data` is a category label; `Save & Report` is a verb.
- [ ] **Check whether the save controls are duplicated per tab** — there is both a `stressDataGroup`
      and a `loadDataGroup`. If both carry Save, consolidate to one place.
- [ ] **Decide where Speed Control lands.** Either its own group directly under Motor Control, or
      folded into it as the manual-jog speed — the strain-rate test and the advanced modes already
      carry their own speed fields, so the top-level one is only for jogging. The circular gauge is a
      *readout*, not a control, and could move to the live-readout area either way.

### Narrow screens — the panel must survive a 13–14" laptop

Today, narrowing the control column **hides elements and makes them unselectable**. Raised
2026-08-27. Set a concrete target and test against it, rather than "looks fine on my monitor":

> **Design target: the control column works down to ~320 px, on a 1366×768 screen at 150 % Windows
> scaling.** That is the real constraint a 13–14" student laptop imposes.

- [ ] **Root cause — 69 hard size constraints in `ui/utm_mainwindow.ui`** (`minimumSize`,
      `maximumSize`, explicit `<width>`). These are what stop the panel shrinking gracefully: a
      layout cannot compress below the sum of its children's minimums, so it clips instead. **Audit
      all 69**; most should become size *policies*, not fixed pixels.
- [ ] **Move labels ABOVE their controls, left-aligned.** This is the single biggest win for narrow
      widths — a label beside a field doubles the row's minimum width. Qt does it natively:
      `QFormLayout.setRowWrapPolicy(QFormLayout.RowWrapPolicy.WrapAllRows)`. Note only **6**
      QFormLayouts exist across the `.ui` and `main.py` today — nearly every row is a QHBoxLayout
      with the label welded beside the control, which is exactly why they squish.
- [ ] **Specimen first row holds too much** — `Settings:` + profile combo + `Load` + `Save…` +
      `Infill %` + spinner, all on one line. Split: profile and its two buttons on one row, infill on
      its own.
- [ ] **`Auto-stop at fracture` loses visibility** wedged between `Prepare test` and `Fracture test`.
      **Move it above the two buttons**, on its own row. It is a mode that governs both, not a peer
      of either — the position should say so.
- [ ] **Advanced test modes: `Low` and `High` side by side** squish together. Same fix — label above
      control, and let the pair stack when there is no room.
- [ ] **Never let a control become unreachable.** If a group genuinely cannot fit, it must wrap or
      the panel must scroll — clipping a control so it cannot be clicked is the one outcome to
      design out. Check every group at the target width.
- [ ] **Test at 125 % and 150 % Windows DPI scaling**, not just 100 %. Fixed pixel sizes are exactly
      what breaks under scaling, and student laptops are rarely at 100 %.

### Working on the UI with no machine attached — yes, and here is the setup

**You do not need the rig.** Confirmed: the app starts with no serial link and no camera, and
**disabled widgets still occupy their full geometry** — so every layout, truncation and clipping bug
is visible while disconnected. Layout work is fully doable on a laptop at midnight.

**Qt Designer is NOT the workflow** (operator's call, 2026-08-27) — changes are verified by
running the app end-to-end. That is the right call anyway: the panel is built two ways, with some
widgets created in `main.py` and inserted at runtime relative to others, so Designer only ever
showed part of the truth.

- [ ] **Edits go straight to the `.ui` XML and `main.py`, verified by launching.** For a structural
      change, an offscreen build is a fast pre-check before a visual one —
      `QT_QPA_PLATFORM=offscreen` plus constructing `UTMApplication` exercises every runtime layout
      builder without a rig, a camera or a window. That is how the E-STOP move was verified.
- [x] **DONE 2026-08-28 — `--demo` flag.** `python main.py --demo` renders every control in
      its enabled state with no rig. Verified offscreen: **9/9 gated controls disabled without
      the flag, 9/9 enabled with it**; `send_command` is replaced so a demo session cannot
      reach a port (returns False, logs `[DEMO] not sent: ...`); title reads `DEMO MODE (no
      hardware)`. It ORs into the gate rather than forcing `self.connected`, because the
      connection monitor rewrites that flag on a timer and would undo it.

<details><summary>original request</summary>

- **Add a `--demo` flag so the panel renders in its ENABLED state.** Twelve controls gate on
      `connected`, so a disconnected app shows half the panel greyed out and you cannot judge it.
      **There are currently no CLI flags at all** — `main.py:7487` is a bare
      `QApplication(sys.argv)` — so this is a clean, self-contained addition: parse one argument,
      force the connected state true, refuse to send serial. Cheap, and it is what makes a weekend
      of UI work actually productive.

</details>
- [ ] **Load an existing CSV** to populate the plots, cropping and data groups without hardware —
      CSV import already restores DIC data and calibration.
- [ ] **The DIC post-processing tab runs fully offline** against recorded video, so that whole tab
      can be designed and tested with no rig at all.

### ✅ DONE 2026-08-28 — Connection UX: autoconnect, and three real bugs

**Autoconnect.** The app now finds and opens the rig at launch with no scanning and no
picking. Two stages, and only the second proves anything: USB **VID/PID narrows** the
candidates, the firmware **handshake confirms** (`Welcome to Mirzas...`, which
`serial_manager` already tested for). `--no-autoconnect` opts out; it falls back silently to
the manual controls when nothing is found.

**Three bugs fixed along the way:**

1. **Connect could be clicked with no port selected**, and the resulting
   `Error: No COM port selected` went to the Console — invisible from any other tab, so it
   read as "the button does nothing". The switch is now **disabled** unless a port exists,
   with a tooltip saying to scan.
2. **An in-flight attempt could not be stopped.** The toggle-off branch only acted
   `if self.connected or port_open`, so an attempt against a dead port left the worker thread
   and the handshake timer running with the switch stuck on. Added
   `SerialManager.cancel_connect()`, and the toggle now calls it.
3. **Connecting did not show the Console**, where the entire connection story is written.
   It now switches tabs on connect and on the no-port error.

**Field note — the rig board is a CH340, not a CP2104.** Live scan: `COM3` reports
`0x1A86:0x7523`. **CH340 chips have no USB serial number** (`serial=None` on this board), so
the "pin the serial number to survive COM renumbering" idea in the original plan **does not
work here**. VID/PID plus the handshake is what identifies the rig. Worth re-checking after
the USB hub arrives, since renumbering is exactly what a hub causes.

- [ ] **Try it against the real rig.** Verified offscreen with the connect call stubbed, so no
      port was opened and the ESP32 was never DTR-reset. The identification is proven on live
      hardware (`COM3` correctly picked out of three ports); the actual open is not.
- [ ] **Decide whether autoconnect should retry** if the rig is plugged in *after* launch.
      Currently it runs once at startup. A student who forgets the cable has to press Scan.

---

## Deployment — one file, no install (for discussion)

Goal: a student downloads one `.exe` and runs it. `tools/build_exe.py` (PyInstaller) already exists
but has never been used in anger. Raised 2026-08-27.

### ✅ DONE 2026-08-27 — `deploy/` and a working `build_exe.py`

A double-clickable icon now exists, and the PyInstaller script actually runs.

| file | what |
|---|---|
| `deploy/install.ps1` | Windows. venv + deps + Desktop and Start-Menu shortcuts, `pythonw.exe` so there is no console window. `-Rig` (with pypylon) or default analysis profile. |
| `deploy/install.sh` | macOS `.command` / Linux `.desktop`. Same two profiles. Lower priority, as agreed. |
| `deploy/make_icon.py` | generates `utm.ico` + `utm.png` — a stress-strain curve to fracture, drawn per size so it reads at 16 px. There was no icon in the repo at all before. |

**`tools/build_exe.py` was BROKEN and is now fixed.** It still assumed it sat beside `main.py`, but
it moved into `tools/` in the 2026-08-25 reorganisation — so `MAIN_PY` resolved to
`tools/main.py` and `get_version()` raised `FileNotFoundError` at import. Fixed, plus: it now
bundles `ui/help/` (without which every `?` diagram is silently blank), sets the icon, and takes
`--analysis` to exclude pypylon for the student build.

- [ ] **Run `install.ps1` end-to-end on the rig PC** — parse-checked and the shortcut mechanism is
      verified, but the full venv-and-install path has not been executed.
- [ ] **Actually build an exe and test it on a clean Windows machine** with no Python and no Pylon.
      Still the only test that counts, and `__file__` paths under a frozen build remain unproven.

### ⭐ Installer — built, NOT yet run end-to-end

Files exist and are parse-checked; **none of it has been executed against a real install.**

- [ ] **Run `deploy\install.ps1` on the rig PC.** Creates `.venv`, installs deps, puts a
      Desktop + Start Menu icon. Parse-checked and the `.lnk` mechanism is verified, but the
      venv-and-pip path has never been executed.
- [ ] **Run `deploy\install.ps1 -Rig` vs the default analysis profile** and confirm the
      analysis one really does start with no pypylon. *(The import guard is done and tested —
      see below — so this should now work.)*
- [ ] **Test `deploy/bootstrap.ps1`** — the `irm ... | iex` one-liner. **Blocked until the
      merge is pushed**: it clones `cenmir/UTM`, which is still at the old head, so the raw
      URL 404s today.
- [ ] **Build an actual exe** with `tools/build_exe.py --analysis` and test it on a clean
      Windows machine with no Python and no Pylon. Still the only test that counts.
- [ ] **Fix `__file__` under PyInstaller BEFORE building** — see below. The exe will appear to
      work and then fail silently without it.
- [ ] **`install.sh` (macOS/Linux) is untested.** Low priority, as agreed.

**✅ Prerequisite done 2026-08-28: pypylon import is now optional.** `camera_manager.py` did
`from pypylon import pylon` at module level and `main.py` imports `CameraManager` at module
level, so a machine without pypylon **could not start the app at all** — the `--analysis`
build would have compiled and then crashed on launch. All four `pylon.*` uses sit behind
`connect_camera()`, so the import is now soft (`PYLON_AVAILABLE`) and that one entry point
refuses cleanly with a message pointing at the post-processing tab. Verified by blocking
pypylon with a `find_spec` hook: app imports, window builds, `connect_camera()` returns False.

### The framing decision: this is TWO builds, not one

- [ ] **Decide the target before building anything.** They need different things:

| Build | For | pypylon | Notes |
|---|---|---|---|
| **Rig build** | the lab PC that drives the machine | **yes** | One machine, one setup. An installed venv is arguably better than an exe here — easier to patch mid-campaign. |
| **Analysis build** | the ~40 student laptops | **no** | Post-processing tab, CSV load, plots, Generate report. **This is the one worth shipping as a single exe** — and dropping pypylon removes the hardest dependency by far. |

`utm_analysis.py`, `utm_registry.py`, `utm_dic.py`, `control_policies.py` and `utm_recipes.py` are
**deliberately stdlib-only**, so the entire offline path already runs with no camera stack. The
analysis build is a much smaller problem than the rig build.

### The trap that will break the first exe you make

- [ ] **`__file__`-derived paths do not survive PyInstaller.** `CAPTURE_ROOT`, `UI_FILE`, the
      `ui/help` lookup and `utm_recipes.RECIPES_DIR` are all built from `__file__`, which under a
      frozen one-file build points into a **temporary extraction directory** that is deleted on exit.
      Per the module README these paths **fail silently** — no exception, just a capture that never
      appears or a blank help image. Route all four through a `sys._MEIPASS`-aware helper for
      read-only assets, and an explicit user-data directory for anything written.

### The rest

- [ ] **Windows SmartScreen will flag an unsigned exe** downloaded by 40 students, and PyInstaller
      one-file builds draw antivirus false positives. Either get it signed, or write the
      click-through into the guide and warn the students before they panic.
- [ ] **One-file vs one-folder.** One-file re-extracts on every launch — expect 5–15 s of startup
      with PyQt6 + matplotlib bundled. One-folder starts fast but is a folder, not "a single file".
      A zipped one-folder build is the usual compromise; decide which promise matters more.
- [ ] **Pin the version in the filename** (`build_exe.py` already reads `__version__` from
      `main.py`). Over seven weeks you will ship more than one build, and you need to know which one
      a student is reporting a bug against.
- [ ] **Test on a clean Windows machine** with no Python and no Pylon. That is the only test that
      counts, and it is the one everybody skips.
- [ ] **Decide how students get their data off the rig PC** — the analysis build is only useful if
      they can take a CSV home. USB stick, network share, or the report PDF alone.

---

## ⚙️ Firmware — next revision

No firmware work is currently scheduled; version sits at **1.3.1**. These are the items for the
next revision, whenever it happens. Neither blocks the student campaign.

### Read the second AS5600 — crosshead skew detection  ⭐ the one worth doing

**The encoder is already fitted, wired through the TCA9548A and initialised — and never read.**

- `D32_Firmware/src/main.cpp:35` — `#define SENS_IDX 0`, and `ProcessSensors()` only ever reads
  that one channel, so the reported position is **one side's opinion**.
- `D32_Firmware/src/main.cpp:23-24` — **one** `STEP_PIN 14` / `DIR_PIN 27` and **one**
  `MoToStepper`; both TMC2160 drivers take the same pulse train in parallel. There is no
  independent control of the two sides and no correction if they diverge.
- `Sensors` already exposes `readTotalPosition(int)` and carries `amsOffsets[2]`. The capability is
  built and paid for; nothing new has to be wired.

If one side binds and skips steps the crosshead **racks**, and today nothing detects it. That is
precisely the S15 fault mode (`docs/TEST_FAILURES.md`), and the instrument that would have caught
it in seconds is already bolted to the machine.

- [ ] **Read channel 1 alongside channel 0** and expose the difference over serial as its own field.
- [ ] **Log skew as a CSV column** — it then becomes a health trace on every test from then on, and
      a slow drift across the 7-week campaign is exactly the signal §1 of `MECHANICAL_TODO.md` is
      trying to catch by hand.
- [ ] **Add a skew threshold**: warn, then halt. Strictly better than the software stall guard,
      which sees the symptom (crosshead frozen) rather than the cause (sides diverging).
- [ ] **Testing plan — this needs deliberate validation, not just a code change:**
      - Bench test first, motors free, no specimen: confirm both channels track and that the
        difference sits at a stable near-zero with a known noise band. **Establish that band before
        setting any threshold**, or the threshold is a guess.
      - Confirm the multiplexer channel select is correct for both — `tcaselect()` must run before
        every read, and a wrong channel returns the *other* encoder's angle, which looks like
        perfect agreement rather than an error.
      - Verify the cumulative-position offsets (`amsOffsets[2]`) behave independently across a
        power cycle for both channels; only channel 0's path has ever been exercised.
      - Then induce a known skew deliberately (one side hand-cranked, machine disabled) and confirm
        both the reading and the halt fire at the expected magnitude.
- [ ] **Watch the I2C budget.** `ProcessSensors()` runs on a 50 ms cadence and the load-cell loop
      shares the bus; a second `tcaselect` + read per cycle roughly doubles the encoder I2C traffic.
      Measure the loop time after, not before — the `# DIC Loop` header line already reports it.

### Also

- [ ] **Consider exposing loop timing over serial** as a first-class field rather than a header
      comment, so a slow loop is visible live rather than found afterwards in a CSV.

---

## 🔵 P2 — Research (see ROADMAP for the full detail)

- [ ] **Why did DIC delivery slow?** ROADMAP §3a item 6. Narrowed to downstream-of-detection and
      correlated with Black mode; n = 3. **Confirm on the next Black run.** Gates the P0 marker
      decision above for any future campaign.
- [ ] **Ask MOT for their load or crosshead-displacement channel.** Turns the extensometer
      comparison into a real scale check by cancelling the compliance term. Cheap, and the only
      thing left on that thread.
- [ ] **T6.6 damage curve** — fresh 50 % specimen, 400→1100 N, 12 sine cycles, one uninterrupted
      run. The only route to D = 1 − Eᵢ/E₀. ~40 min.
- [ ] **Deck slides for SF11/12/13/18/19** — two overview slides first, then per-feature slides as
      screenshots arrive. SF18 is blocked on the lighting problem.
- [ ] **Multi-marker Poisson / true Cauchy** — maths ready in `utm_dic.py`; needs a 4-marker
      specimen preset and camera wiring.

---

## Housekeeping

- [ ] `README.md` points at `Software/UTM_PyQt6/dic_replay.py`; the file is at
      `Software/UTM_PyQt6/tools/dic_replay.py`. Stale since the 2026-08-25 reorganisation.
- [ ] Registry integrity check — must print `0 unresolved`, run **from the repository root**:
      ```
      python -c "import json,os; r=json.load(open('Software/UTM_PyQt6/registry.json')); print(sum(1 for x in r if not os.path.isfile(x['csv'])),'unresolved of',len(r))"
      ```

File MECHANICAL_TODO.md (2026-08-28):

# UTM — Mechanical Health TODO

**Opened 2026-08-27.** Everything in `TODO.md` and `Software/UTM_PyQt6/docs/ROADMAP.md` is software;
the development effort to date has been almost entirely software. This file is the mechanical
counterpart, and it is deliberately separate so it does not get buried under feature work again.

**Status: nothing here is scheduled.** It is a standing list for when rig time exists. Ordered by
what the existing data says is most likely to be costing accuracy, not by effort.

> The one item with a deadline is **§1 — the weekly check**, because the 7-week student campaign
> starts Monday 2026-08-31 and §1 is the failure mode that 40 mount/unmount cycles actually causes.

---

## 1. Alignment and fasteners — the known, recurring fault ⚠️ weekly during the campaign

The only mechanical failure on record. Load holders worked loose → crossheads sat out of alignment
→ the trapezoidal screws bound → the motor spent its torque on the machine instead of the specimen
and stalled at 2.6 kN. Diagnosed and fixed 2026-08-12 (re-aligned, re-tightened, screws lubricated).
`Software/UTM_PyQt6/docs/TEST_FAILURES.md` S15 has the write-up and the evidence trail.

**This is a wear-and-use fault, not a one-off.** Mounting and unmounting specimens is exactly what
loosens the holders, and ~40 student groups will do it a lot.

- [ ] **Weekly during the campaign:** load-holder fastener torque · crosshead alignment and
      squareness to the screws · screw lubrication.
- [ ] **Write down the torque values** once measured, so "tight" stops being a judgement call.
      Right now the correct state of this machine exists only as tacit knowledge.
- [ ] **Treat a stall-guard trip as a mechanical alarm.** If the guard fires, the first check is
      alignment and lubrication — not the motor, not the drivers, not the software.

---

## 2. Two motors share one step signal, and only one encoder is read ← highest-value fix

Straight from the firmware:

- `D32_Firmware/src/main.cpp:23-24` — **one** `STEP_PIN 14` / `DIR_PIN 27`, and **one**
  `MoToStepper stepper`. Both TMC2160 drivers are fed the same pulse train in parallel. There is no
  independent control of the two sides and no correction if they diverge.
- `D32_Firmware/src/main.cpp:35` — `#define SENS_IDX 0`, and `ProcessSensors()` only ever reads
  that one. **The second AS5600 is fitted, wired through the multiplexer and initialised in the
  `init(i)` loop — and then never read.** `Sensors` already exposes `readTotalPosition(int)` and
  carries `amsOffsets[2]`, so the capability is built and paid for.

**Why this matters mechanically.** If one side binds and its motor skips steps, the crosshead
**racks** — and nothing detects it. The reported position is one side's opinion. This is precisely
the S15 fault mode, and the instrument that would have caught it in seconds is already bolted to
the machine.

- [ ] **Read encoder 1 and report its difference against encoder 0.** The divergence between them is
      a direct, quantitative measure of racking and binding. Log it as a column and it becomes a
      health trace on every test run from then on.
- [ ] **Add a skew threshold** that warns, then halts. A cheap firmware-side safety net, strictly
      better than the software stall guard because it catches the cause rather than the symptom.
- [ ] **Check static squareness independently** — dial indicator across the crosshead at both
      screws, at several heights of travel. Establishes whether racking is dynamic (skipped steps)
      or built in.

---

## 3. Machine compliance — 71–81 % of crosshead travel never reaches the specimen

The MOT extensometer comparison (ROADMAP §3a) established that **only 19–29 % of crosshead motion
reaches the gauge**, and that the residual low-strain non-linearity is *the rig, not the material*:
our local strain rate climbs through the ramp while the XT-205's is flat from the moment it engages.

DIC makes this harmless for strain — that is the whole point of measuring on the specimen — but it
means every crosshead-derived number carries the machine in it, and it is a large number to not
understand.

### The specimen holder is printed 100 % PLA — that is almost certainly where it goes

The frame is 80×80 aluminium extrusion: E ≈ 70 GPa with a large second moment. At 3.8 kN it is
effectively rigid and is **not** the source. The **form-holder that grips the specimen is printed
PLA** — the same material as the specimen, in series with it, carrying the full test load.

Bulk stiffness alone does not explain the loss. A thick PLA holder with, say, 400 mm² of effective
section over a 50 mm load path is ~20 000 N/mm, which would cost only ~12 %. Reaching the observed
~870 N/mm series stiffness needs something far softer, so **the dominant term is local contact
crushing and bedding-in, not bulk holder compliance** — which is exactly what is expected and
observed.

That single fact explains the shape of the curve, not just its size: contact area grows as the
material crushes, so stiffness *increases* with load. That is the toe region, and it is why "our
local strain rate CLIMBS through the ramp while theirs is flat from the moment it engages."

- [ ] **Calculate bearing stress at the contact faces.** 3800 N divided by the actual bearing area
      at each PLA contact — specimen tab against holder, holder against its pins or bolts. PLA
      yields around 50–60 MPa, so anything under ~70 mm² of bearing area is **plastically crushing
      on every test**. One calculation, and it tells you whether the deformation is elastic and
      repeatable or permanent and accumulating.
- [ ] **Check the print orientation of the holder.** Printed PLA is anisotropic and layer adhesion
      is the weak direction. If the load pulls across layer lines rather than along them, that is
      both the compliance path and the eventual failure plane.
- [ ] **Measure the compliance curve with a rigid dummy specimen.** A steel bar of the same grip
      geometry, pulled the same way. **Be precise about what this isolates:** the dummy is still
      gripped by the PLA holder, so the curve is *frame + drivetrain + holder + contact*, with only
      the specimen removed. That is still the number you want — it is everything that is not the
      specimen — but it does not exonerate or implicate the holder on its own. To separate the
      holder, run the dummy again in a metal holder if one can be made.
- [ ] **Then separate the rest** one at a time: grip slip (mark the specimen at the jaw line) ·
      specimen shoulder deformation · frame flex · bearing axial play · screw and gearbox backlash.

### Consequences that are easy to miss

- [ ] **PLA creeps at room temperature, and the holder is under full load for the whole test.**
      This matters most for the *time-based* modes — **creep, relaxation, and the long dwells in
      staircase**. Establish whether the measured decay is specimen behaviour or holder creep
      before any of those results are published. A relaxation run against a rigid dummy would
      answer it directly: whatever force decay appears with no specimen present is the holder.
- [ ] **The compliance will drift across the 7-week campaign.** If the contact faces are crushing
      plastically, the holder gets progressively softer as surfaces bed in and yield, so week-1 and
      week-7 groups do not share a machine. **DIC protects the results** — strain is measured on the
      specimen — but any crosshead-derived quantity drifts, and this is another reason the student
      profile must pin the strain source to DIC.
- [ ] **Inspect the holder for cracking periodically**, especially around pin and bolt holes where
      stress concentrates. A PLA part taking 3.8 kN forty-plus times is a fatigue candidate, and the
      frame has stored elastic energy to release if it lets go.
- [ ] **Consider a metal holder** as the eventual fix. Not urgent — the machine measures correctly
      as it stands, because DIC bypasses the whole problem — but it would recover most of the lost
      travel, remove the creep question from the time-based modes, and stop the drift.

---

## 4. Backlash and lost motion — matters for the reversing test modes

Position is measured at the **motor shaft**, upstream of both the 20:1 EPL-Q64 planetary gearbox and
the Tr22x5 screw. Anything either of those loses is invisible to the position reading.

On a monotonic tensile pull this mostly does not matter. On **cyclic, staircase and relaxation**
modes it does — every direction reversal crosses the backlash dead zone, and the crosshead does not
move while it does. The note that "direct reversal auto-decels ~1 s" is a control observation
sitting on top of an unmeasured mechanical one.

- [ ] **Measure total lost motion at the crosshead** on reversal, with a dial indicator, at several
      loads. Planetary gearboxes of this class are typically 15–30 arcmin; trapezoidal screws add
      their own.
- [ ] **Decide whether the cyclic results already on record need a backlash caveat.**
- [ ] **Check the 4 × SKF-6005-2Z axial preload.** Deep-groove bearings taking a thrust load will
      have axial play unless preloaded, and that play sits directly in the load path.

---

## 5. Load train and load-cell health

- [ ] **Check for off-axis loading.** Any misalignment between the grips and the load cell puts a
      bending moment into a cell meant to read axial force. Same misalignment family as §1 — check
      at the same time.
- [ ] **Re-run the two-point calibration with a known reference weight**, at least once mid-campaign
      and after any mechanical work. Seven weeks and ~40 mountings is long enough to drift.
- [ ] **Record that nothing is near a ceiling.** Anyload 101BH-3t = 3 t ≈ 29 kN; the drivetrain is
      good for ~15 kN; a PLA fracture is ~3.8 kN. Worth writing down so the "torque ceiling" story
      does not resurface a third time.

---

## 6. Frame

- [ ] **T-slot fastener torque across the 80×80 extrusion joints.** Frame flex feeds straight into
      §3, and extrusion joints relax over time.
- [ ] **Look for stick-slip at 0.1 mm/s.** At ~24 RPM at the motor the drivetrain is deep in its
      full-torque region, so any judder is mechanical, not electrical.

---

## Reference

| | |
|---|---|
| Motors | 2 × Nema 23 AMP57TH76-4280, 1.85 Nm stall |
| Gearboxes | 2 × EPL-Q64 i20 (20:1 planetary) |
| Screws | 2 × Tr 22×5 TH22 trapezoidal, 5 mm pitch |
| Bearings | 4 × SKF-6005-2Z deep groove |
| Load cell | Anyload 101BH-3t (3 t ≈ 29 kN) |
| Encoders | 2 × AS5600 via TCA9548A at 0x70 — **only channel 0 is read** |
| Drivers | 2 × MKS TMC2160_57 — **both on one step/dir signal** |
| Frame | Aluminium extrusion 80×80 |
| Drivetrain capability | ~15 kN · PLA fracture ~3.8 kN (~25 %) |

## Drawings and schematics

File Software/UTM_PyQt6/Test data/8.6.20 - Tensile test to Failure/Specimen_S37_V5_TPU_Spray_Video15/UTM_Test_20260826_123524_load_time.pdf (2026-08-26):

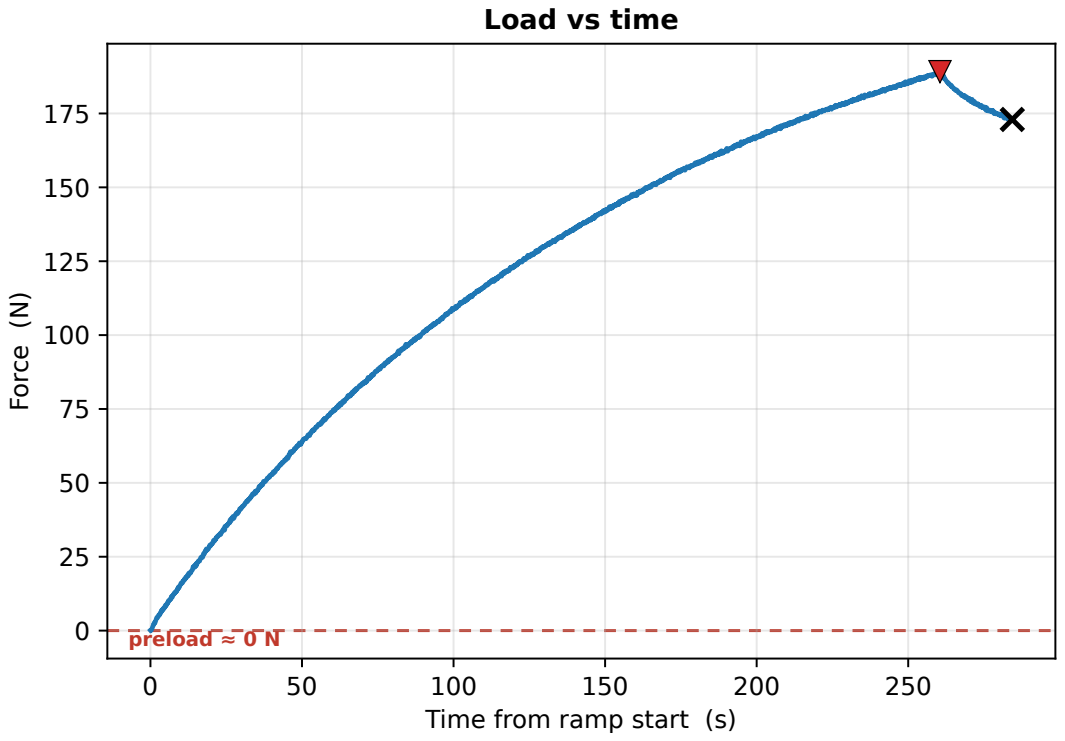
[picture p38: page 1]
Force (N); preload ≈ 0 N

Load vs time

Time from ramp start (s)

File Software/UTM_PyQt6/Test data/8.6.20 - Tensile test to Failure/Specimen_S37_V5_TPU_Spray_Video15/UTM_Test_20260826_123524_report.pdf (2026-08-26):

## 2.4 MPa

## 0.7 MPa

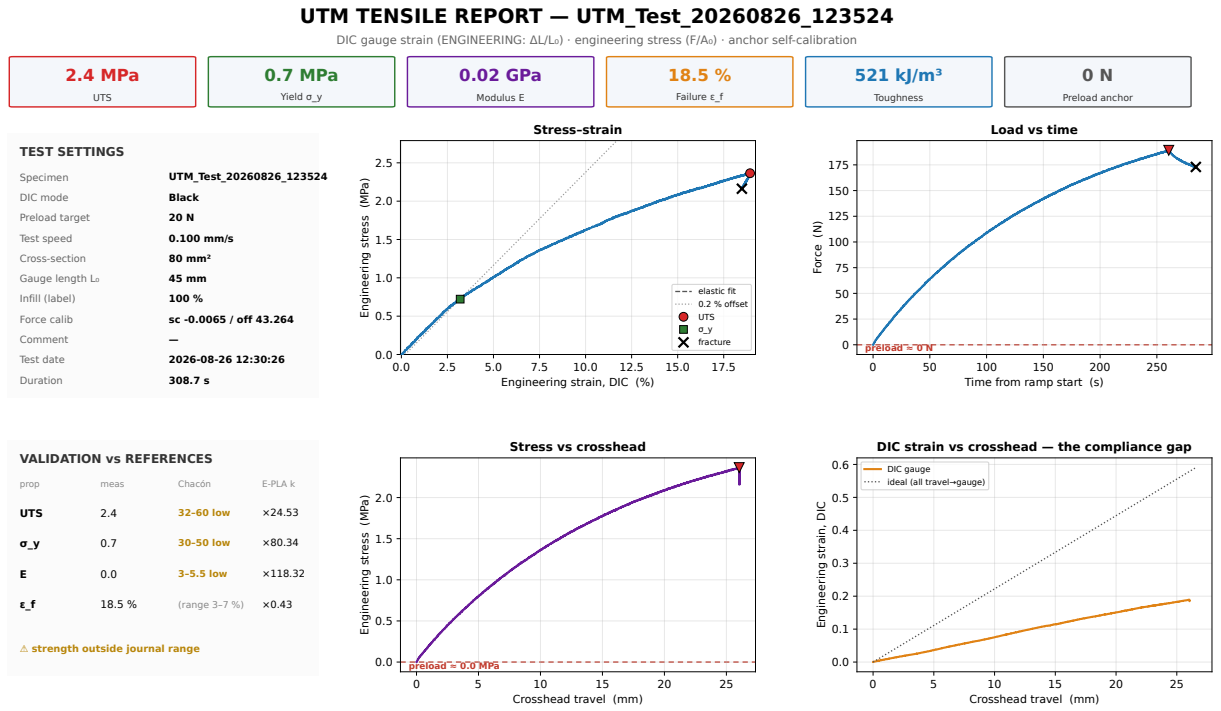
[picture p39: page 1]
UTS; Yield σ_y; 0.02 GPa; Modulus E; Failure ε_f; Toughness; Preload anchor; TEST SETTINGS; Specimen; UTM_Test_20260826_123524; DIC mode; Black; Preload target; Test speed; Cross-section; 80 mm²; Gauge length L₀; Infill (label); Force calib; sc -0.0065 / off 43.264; Comment; Test date; Duration; prop; meas; Chacón; E-PLA k; 32–60 low; 30–50 low; 3–5.5 low; (range 3–7 %); Stress–strain; Force (N); preload ≈ 0.0 MPa

UTM TENSILE REPORT — UTM_Test_20260826_123524

DIC gauge strain (ENGINEERING: ΔL/L₀) · engineering stress (F/A₀) · anchor self-calibration

Load vs time

Engineering stress (MPa)

elastic fit 0.2 % offset UTS

σ_y fracture

preload ≈ 0 N

Engineering strain, DIC (%)

Time from ramp start (s)

Stress vs crosshead

DIC strain vs crosshead — the compliance gap

VALIDATION vs REFERENCES

DIC gauge
ideal (all travel→gauge)

Engineering strain, DIC

⚠ strength outside journal range

Crosshead travel (mm)

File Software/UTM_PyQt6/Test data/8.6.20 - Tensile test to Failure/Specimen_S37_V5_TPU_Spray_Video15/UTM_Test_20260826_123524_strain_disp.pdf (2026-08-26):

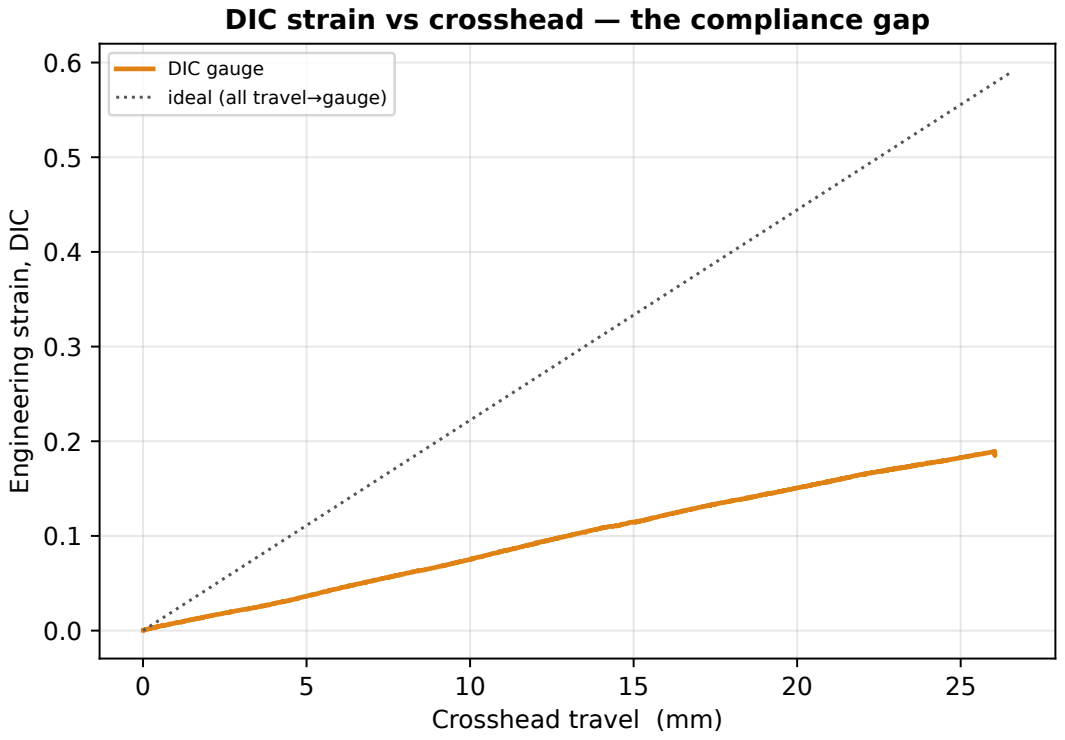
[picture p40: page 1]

DIC strain vs crosshead — the compliance gap

DIC gauge
ideal (all travel→gauge)

Engineering strain, DIC

Crosshead travel (mm)

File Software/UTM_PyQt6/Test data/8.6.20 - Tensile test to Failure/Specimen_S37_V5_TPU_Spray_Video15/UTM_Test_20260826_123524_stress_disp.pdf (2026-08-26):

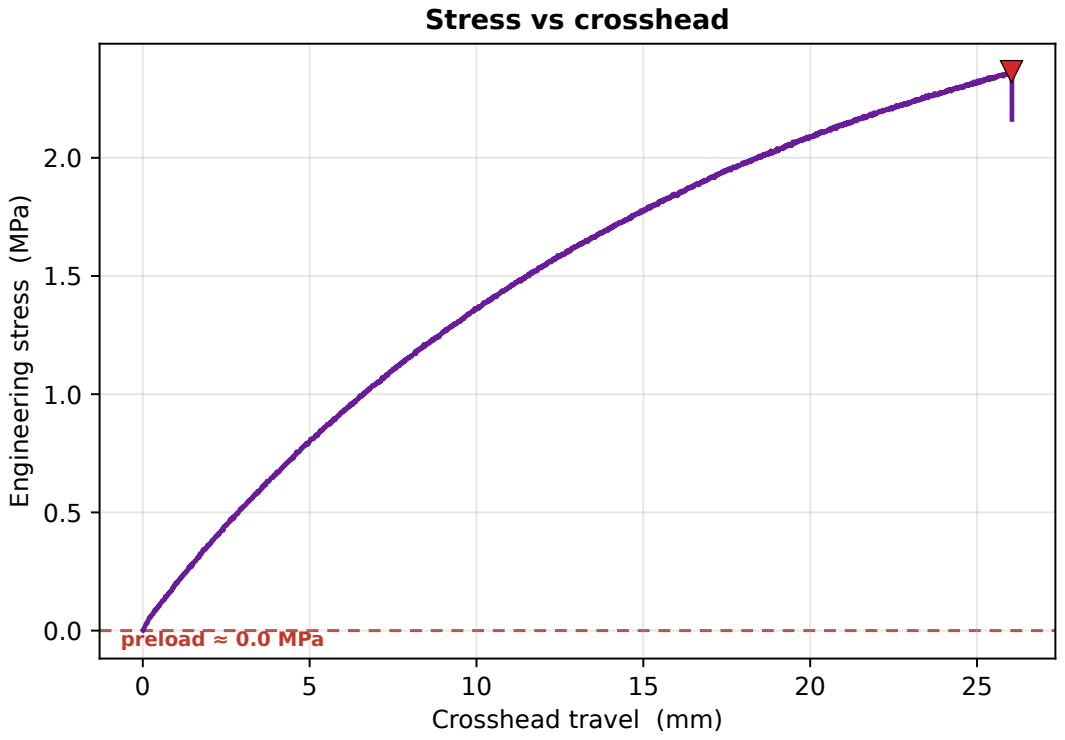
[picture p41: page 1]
preload ≈ 0.0 MPa

Stress vs crosshead

Engineering stress (MPa)

Crosshead travel (mm)

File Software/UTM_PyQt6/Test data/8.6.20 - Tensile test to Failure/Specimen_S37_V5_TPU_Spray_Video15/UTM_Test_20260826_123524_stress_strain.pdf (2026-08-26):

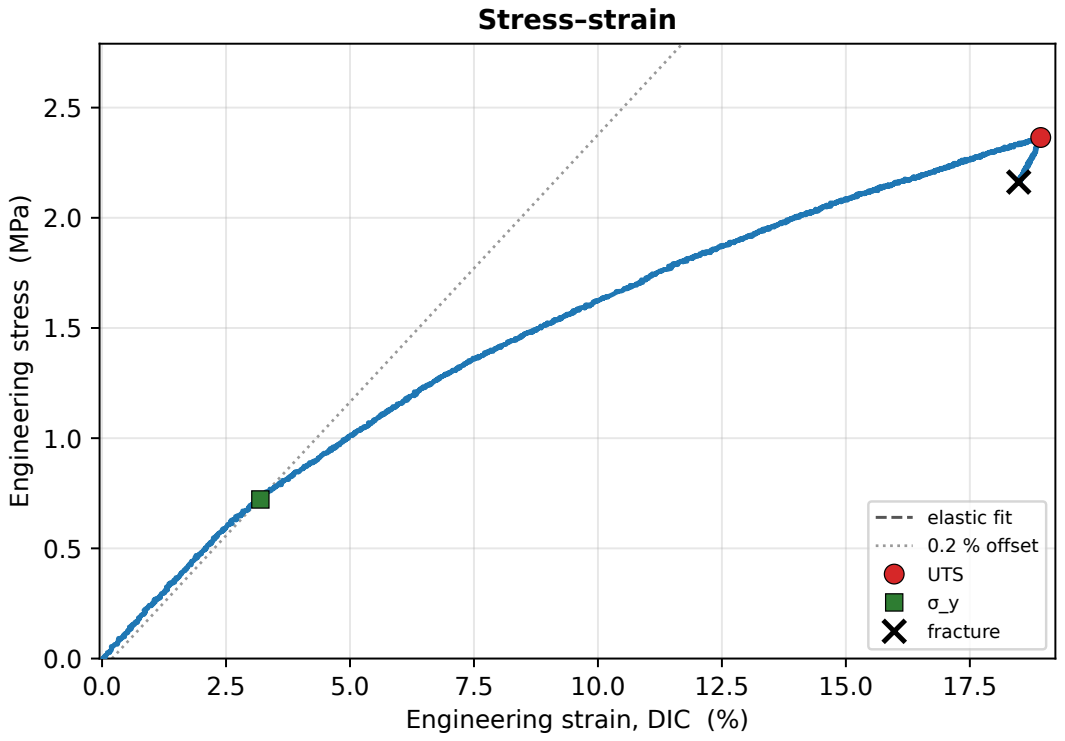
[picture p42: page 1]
Stress–strain

Engineering stress (MPa)

elastic fit 0.2 % offset

UTS σ_y fracture

Engineering strain, DIC (%)

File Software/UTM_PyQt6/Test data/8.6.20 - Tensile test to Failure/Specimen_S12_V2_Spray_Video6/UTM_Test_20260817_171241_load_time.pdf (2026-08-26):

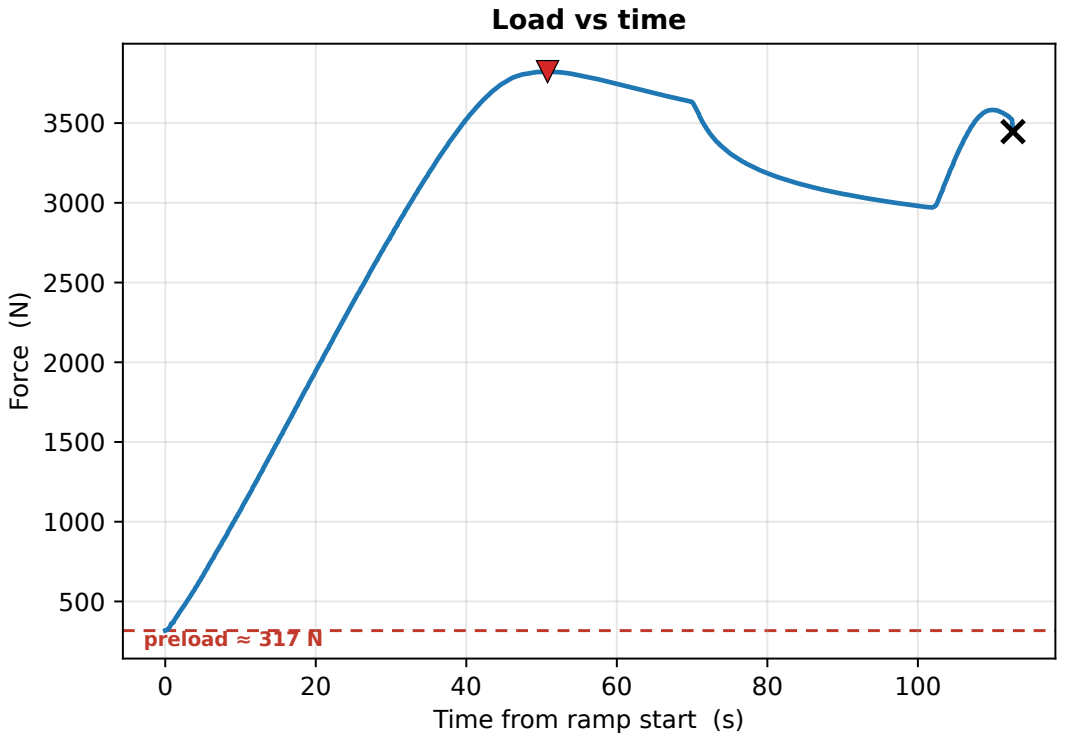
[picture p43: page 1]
Force (N); preload ≈ 317 N

Load vs time

Time from ramp start (s)

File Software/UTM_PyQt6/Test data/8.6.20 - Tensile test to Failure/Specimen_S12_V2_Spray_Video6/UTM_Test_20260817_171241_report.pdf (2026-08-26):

## 47.8 MPa

## 42.7 MPa

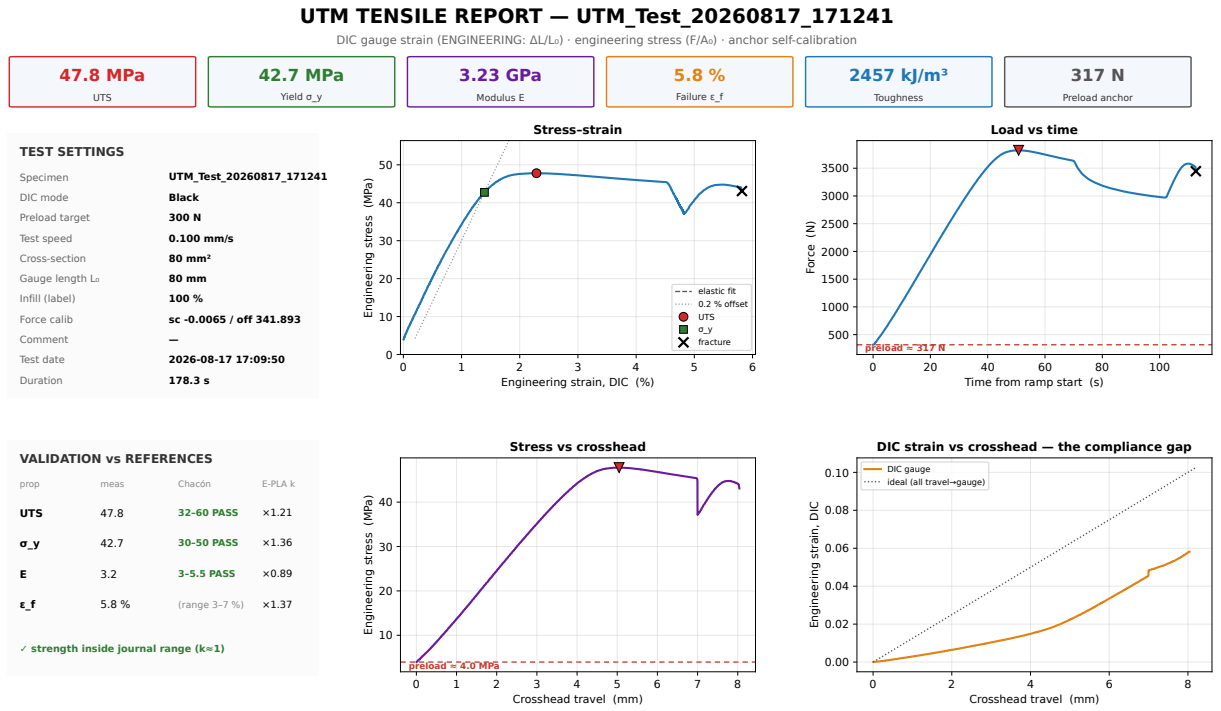
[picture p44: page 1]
UTS; Yield σ_y; 3.23 GPa; Modulus E; Failure ε_f; Toughness; Preload anchor; TEST SETTINGS; Specimen; UTM_Test_20260817_171241; DIC mode; Black; Preload target; Test speed; Cross-section; 80 mm²; Gauge length L₀; Infill (label); Force calib; sc -0.0065 / off 341.893; Comment; Test date; Duration; prop; meas; Chacón; E-PLA k; 32–60 PASS; 30–50 PASS; 3–5.5 PASS; (range 3–7 %); Stress–strain; Force (N); preload ≈ 4.0 MPa

UTM TENSILE REPORT — UTM_Test_20260817_171241

DIC gauge strain (ENGINEERING: ΔL/L₀) · engineering stress (F/A₀) · anchor self-calibration

Load vs time

Engineering stress (MPa)

elastic fit 0.2 % offset UTS

σ_y fracture

preload ≈ 317 N

Engineering strain, DIC (%)

Time from ramp start (s)

Stress vs crosshead

DIC strain vs crosshead — the compliance gap

VALIDATION vs REFERENCES

DIC gauge
ideal (all travel→gauge)

Engineering strain, DIC

✓ strength inside journal range (k≈1)

Crosshead travel (mm)

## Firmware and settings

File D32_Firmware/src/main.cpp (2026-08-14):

#include <Arduino.h>
#include <HX711.h> // https://github.com/RobTillaart/HX711

#include <Wire.h>
#include <MobaTools.h>
#include "Sensors.h"
#include "CommandHandler.h"

// Define LED_BUILTIN for ESP32 if not already defined
#ifndef LED_BUILTIN
#define LED_BUILTIN 2
#endif

// ============================================
// FIRMWARE VERSION - UPDATE ON EVERY UPLOAD!
// ============================================
const char* FIRMWARE_VERSION = "1.3.1";



#define DATA_PIN    16     // HX711
#define CLOCK_PIN   4      // HX711
#define STEP_PIN   14      // Stepper driver step pin
#define DIR_PIN    27      // Stepper driver direction  pin
#define ENABLE_PIN 26      // Stepper driver enable pin

const int SPEED_SWITCH_PIN = 2; // HIGH is slow
const int UP_BUTTON_PIN    = 17;
const int DOWN_BUTTON_PIN  = 15;

// Safety limits
const int MAX_SPEED_RPM10 = 4500;  // Maximum speed: 450 RPM * 10 = 4500

#define TCAADDR 0x70 // I2C multiplexer adress
#define SENS_IDX 0   // Which sensor to read
#define NUMBER_READINGS 20 // For averaging the speed

bool readLoadCell = false;
bool readSensors = false;
bool readAngle = false;
bool readAngularSpeed = false;

int32_t totalPosition = 0;
float   angularSpeed  = 0;
float angularSpeedBuffer[NUMBER_READINGS];    // Circular buffer for storing readings
int bufferIndex = 0;               // Index to track the position in the buffer
float averageAngularSpeed;      // Averaged angular speed values
long force = 0;

bool speedSwitchState = HIGH; // HIGH is slow and default

HX711 LoadCell;

Sensors sensors; // Rotation sensors

const int STEPS_REVOLUTION = 200*8;
MoToStepper stepper( STEPS_REVOLUTION, STEPDIR ); // Mode is stepdir

// MoToButtons setup for simplified button handling
const byte buttonPins[] = {UP_BUTTON_PIN, DOWN_BUTTON_PIN};
MoToButtons buttons(buttonPins, 2, 20, 500); // 2 buttons, 20ms debounce, 500ms for long press
enum { UP_BTN = 0, DOWN_BTN = 1 }; // Button indices

// Command handler for serial communication
CommandHandler* cmdHandler = nullptr;

// Function declarations
void ProcessSensors();
void ReportLoadCell();
float Average(float buffer[]);
void CheckButtonStates();
void MoveUp();
void MoveDown();
void Stop();
void StartUp();
void ScanI2C();
void ProcessSerialCommands();

void setup() {
  Wire.begin();
  Serial.begin(9600);
  while (!Serial);

  pinMode(LED_BUILTIN, OUTPUT);
  pinMode(SPEED_SWITCH_PIN, INPUT_PULLUP);

  LoadCell.begin(DATA_PIN, CLOCK_PIN, true);
  // Loadcell calibration is done in external software
  //LoadCell.set_offset(4294935301);
  //LoadCell.set_scale(57.144153594970703);

  StartUp();

  // Initialize all sensors
  sensors = Sensors();
  for (int i = 0; i < 1; i++) {
    sensors.init(i);
  }

  // =======================================
  // Stepper config
  // =======================================
  stepper.attach(STEP_PIN, DIR_PIN);

  //stepper.attachEnable(ENABLE_PIN, 10, HIGH);
  // if you want to switch off power when stepper reached position
  
  stepper.setRampLen(100);
  // Ramp length in steps. The permissible ramp length depends on the step rate, and a
  // maximum of 16000 for high step rates. For step rates below 2steps/sec, ramping is no
  // longer possible. If ramplen is outside the permissible range, the value is adjusted.

  pinMode(ENABLE_PIN, OUTPUT);
  digitalWrite(ENABLE_PIN, LOW);
  
  // Initialize command handler
  cmdHandler = new CommandHandler();
  
  cmdHandler->displayHelp();
}

void loop() {
  ProcessSerialCommands();
  CheckButtonStates();

  // Only read data when it is already available.
  if (LoadCell.is_ready()) {
    force = LoadCell.read();
    ReportLoadCell();
  }

  ProcessSensors();
}

void ProcessSensors(){
  static uint32_t delayTimeSensors;
  if ( millis() - delayTimeSensors >= 50 ) {
    delayTimeSensors = millis();
    //sensors.posAndSpeed(0);
    totalPosition = sensors.readTotalPosition(SENS_IDX);

    angularSpeed = sensors.readAngularSpeed(SENS_IDX) / 6; // rpm

    // Add new readings to the circular buffer
    angularSpeedBuffer[bufferIndex] = angularSpeed;

    // Increment the buffer index (wrap around using modulo)
    bufferIndex = (bufferIndex + 1) % NUMBER_READINGS;

    // Calculate the average of the last N readings
    averageAngularSpeed = Average(angularSpeedBuffer);

    if (readSensors) {
      Serial.print(totalPosition); Serial.print("\t");
      Serial.print(angularSpeed); Serial.print("\t");
      Serial.print(averageAngularSpeed); Serial.print("\n");
    }
  }

  
}

void ReportLoadCell(){
  static uint32_t delayTimeLoadCell = 0;
  if (readLoadCell){
    if ( millis() - delayTimeLoadCell >= 50 ) { // Max 20Hz, loadcell should report at 10Hz
      delayTimeLoadCell = millis();
      // Format: "force,mcu_timestamp_ms\n" — MCU timestamp is millis() at sample time
      Serial.print(force); Serial.print(","); Serial.print(delayTimeLoadCell); Serial.print("\n");
    }
  }
}


// Function to calculate the average of the values in a circular buffer
float Average(float buffer[]) {
  float sum = 0.0;
  for (int i = 0; i < NUMBER_READINGS; i++) {
    sum += buffer[i];
  }
  return sum / NUMBER_READINGS;
}


void CheckButtonStates(){
  buttons.processButtons(); // Process button states with debouncing
  
  speedSwitchState = digitalRead(SPEED_SWITCH_PIN);
  
  // UP button - start moving when pressed, stop when released
  if (buttons.pressed(UP_BTN)) {
    MoveUp();
  }
  if (buttons.released(UP_BTN)) {
    Stop();
  }
  
  // DOWN button - start moving when pressed, stop when released
  if (buttons.pressed(DOWN_BTN)) {
    MoveDown();
  }
  if (buttons.released(DOWN_BTN)) {
    Stop();
  }
}

void MoveUp(){
  digitalWrite(ENABLE_PIN, HIGH);
  int speed;
  if (speedSwitchState == LOW){
    Serial.println("Going up fast!");
    speed = MAX_SPEED_RPM10;  // Use max speed (450 RPM)
  } else{
    Serial.println("Going up!");
    speed = 500;  // 50 RPM (slow mode)
  }
  stepper.setSpeed(speed);
  stepper.rotate(-1);
}

void MoveDown(){
  digitalWrite(ENABLE_PIN, HIGH);
  int speed;
  if (speedSwitchState == LOW){
    Serial.println("Going down fast!");
    speed = MAX_SPEED_RPM10;  // Use max speed (450 RPM)
  } else{
    Serial.println("Going down!");
    speed = 500;  // 50 RPM (slow mode)
  }
  stepper.setSpeed(speed);
  stepper.rotate(1);
}

void Stop(){
  Serial.println("Stop and halt!");

  stepper.rotate(0);
}

void StartUp(){

  for (int i=0; i<5; i++){
    delay(500);
    digitalWrite(LED_BUILTIN, HIGH);  
    delay(500);
    digitalWrite(LED_BUILTIN, LOW);
  }

  Serial.println("\n\n\n\n");
  Serial.println("=====================================================");
  Serial.println("Welcome to Mirzas Universal Testing Machine Firmware!");
  Serial.println("=====================================================");
  Serial.println("");
  
  //Serial.print("Using Rob Tillaarts HX711 library version: ");
  //Serial.println(HX711_LIB_VERSION);
  Serial.println();


  ScanI2C();

}

void ScanI2C(){
  int nDevices = 0;

  Serial.println("Scanning I2C...");

  for (byte address = 1; address < 127; ++address) {
    // The i2c_scanner uses the return value of
    // the Wire.endTransmission to see if
    // a device did acknowledge to the address.
    Wire.beginTransmission(address);
    byte error = Wire.endTransmission();

    if (error == 0) {
      Serial.print("I2C device found at address 0x");
      if (address < 16) {
        Serial.print("0");
      }
      Serial.print(address, HEX);
      Serial.println("  !");

      ++nDevices;
    } else if (error == 4) {
      Serial.print("Unknown error at address 0x");
      if (address < 16) {
        Serial.print("0");
      }
      Serial.println(address, HEX);
    }
  }
  if (nDevices == 0) {
    Serial.println("No I2C devices found\n");
  } else {
    Serial.println("Done!\n");
  }
}



void ProcessSerialCommands() {
  if (!cmdHandler->readCommand()) return;
  
  // Toggle commands
  if (cmdHandler->is("LoadCellOn")) {
    readLoadCell = true;
  }
  else if (cmdHandler->is("LoadCellOff")) {
    readLoadCell = false;
  }
  else if (cmdHandler->is("SensorsOn")) {
    readSensors = true;
  }
  else if (cmdHandler->is("SensorsOff")) {
    readSensors = false;
  }
  
  // Get/Query commands
  else if (cmdHandler->is("GetLoad")) {
    Serial.print("Load: ");
    Serial.println(force);
  }
  else if (cmdHandler->is("GetTotalAngle")) {
    Serial.print("Total Angle: ");
    Serial.println(totalPosition);
  }
  else if (cmdHandler->is("GetVelocity")) {
    Serial.print("Velocity: ");
    Serial.print(angularSpeed);
    Serial.print("\t");
    Serial.println(averageAngularSpeed);
  }
  else if (cmdHandler->is("GetVersion") || cmdHandler->is("version") || cmdHandler->is("v")) {
    Serial.print("Firmware Version: ");
    Serial.println(FIRMWARE_VERSION);
  }
  else if (cmdHandler->is("GetSteps")) {
    Serial.print("Total Steps: ");
    Serial.println(stepper.readSteps());
  }
  
  // Motor control commands
  else if (cmdHandler->is("Enable")) {
    digitalWrite(ENABLE_PIN, HIGH);
  }
  else if (cmdHandler->is("Disable")) {
    digitalWrite(ENABLE_PIN, LOW);
  }
  else if (cmdHandler->is("Stop")) {
    stepper.rotate(0);
  }
  else if (cmdHandler->is("EStop")) {
    stepper.stop(); // Emergency stop
  }
  else if (cmdHandler->is("Up")) {
    stepper.rotate(-1);
  }
  else if (cmdHandler->is("Down")) {
    stepper.rotate(1);
  }
  else if (cmdHandler->is("Start")) {
    digitalWrite(ENABLE_PIN, HIGH);
    Serial.println("Going Down with 100rpm");
    stepper.setSpeed(1000);
    stepper.rotate(1);
  }
  
  // Parameterized commands
  else if (cmdHandler->startsWith("SetSpeed")) {
    int rpm10 = cmdHandler->getIntParam();
    // SAFETY: Clamp speed to maximum
    if (rpm10 > MAX_SPEED_RPM10) {
      Serial.print("Warning: Speed limited from ");
      Serial.print((float)rpm10 / 10);
      Serial.print(" RPM to ");
      Serial.print((float)MAX_SPEED_RPM10 / 10);
      Serial.println(" RPM (max)");
      rpm10 = MAX_SPEED_RPM10;
    }
    Serial.print("Setting speed: ");
    Serial.print((float)rpm10 / 10);
    Serial.println(" RPM");
    stepper.setSpeed(rpm10);
  }
  else if (cmdHandler->startsWith("MoveSteps")) {
    long steps = cmdHandler->getLongParam();
    Serial.print("Moving: ");
    Serial.print(steps);
    Serial.println(" steps.");
    stepper.move(steps);
  }
  else if (cmdHandler->startsWith("SetRampLength")) {
    int ramp = cmdHandler->getIntParam();
    Serial.print("Setting ramp length: ");
    Serial.print(ramp);
    Serial.println(" ramp length");
    uint32_t rampLen = stepper.setRampLen(ramp);
    Serial.print("Current rampLen: ");
    Serial.println(rampLen);
  }
}

/*
void Calibrate(){
  Serial.println("\n\n\nCALIBRATION\n===========");
  Serial.println("remove all weight from the loadcell");
  //  flush Serial input
  while (Serial.available()) Serial.read();

  Serial.println("and press enter\n");
  while (Serial.available() == 0);

  Serial.println("Determine zero weight offset");
  LoadCell.tare(20);  // average 20 measurements.
  uint32_t offset = LoadCell.get_offset();

  Serial.print("OFFSET: ");
  Serial.println(offset);
  Serial.println();


  Serial.println("place a weight on the loadcell");
  //  flush Serial input
  while (Serial.available()) Serial.read();

  Serial.println("enter the weight in (whole) grams and press enter");
  uint32_t weight = 0;
  while (Serial.peek() != '\n')
  {
    if (Serial.available())
    {
      char ch = Serial.read();
      if (isdigit(ch))
      {
        weight *= 10;
        weight = weight + (ch - '0');
      }
    }
  }
  Serial.print("WEIGHT: ");
  Serial.println(weight);
  LoadCell.calibrate_scale(weight, 20);
  float scale = LoadCell.get_scale();

  Serial.print("SCALE:  ");
  Serial.println(scale, 15);

  Serial.print("\nuse scale.set_offset(");
  Serial.print(offset);
  Serial.print("); and scale.set_scale(");
  Serial.print(scale, 15);
  Serial.print(");\n");
  Serial.println("in the setup of your project");

  Serial.println("\n\n");
}
*/

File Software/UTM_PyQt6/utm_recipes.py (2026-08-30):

"""Test recipes for the UTM — save/load a named test setup (dimensions, specimen DIC preset,
preload, speed, mode + params) as JSON so a repeat test is one click.

Pure data (no PyQt): the app reads a recipe and applies it to its widgets, or reads the widgets
and saves a new recipe. Recipes live in Software/UTM_PyQt6/recipes/*.json (tracked).

    python utm_recipes.py list
    python utm_recipes.py show "V6 100% infill tensile"
"""
from dataclasses import dataclass, asdict, field, fields
import json, os, sys

RECIPES_DIR = os.path.join(os.path.dirname(os.path.abspath(__file__)), "recipes")


@dataclass
class TestRecipe:
    name: str = "unnamed"
    material: str = "PLA"
    infill_pct: float = 100.0
    specimen_mode: str = "White"          # DIC preset: White (dark dots) / Black (light dots)
    area_mm2: float = 80.0
    # 60 mm: at 80 mm the markers sit on the fillets of this dogbone rather than in
    # the parallel section. See docs/GAUGE_AND_MODULUS.md.
    gauge_mm: float = 60.0
    preload_N: float = 300.0               # matches the GUI default and recipes/Default.json
    test_speed_mm_s: float = 0.1
    # How far the DIC will believe the markers travelled before it calls the separation a LOST
    # MARKER rather than strain, as a percentage. It rides with the profile rather than being a
    # control of its own because it is not an independent choice - it follows from the material,
    # exactly like the preload and the speed beside it. 25 % suits PLA and PETG (they fracture
    # at 4-8 %); an elastomer needs 60 %, which is what recipes/TPU.json carries.
    #
    # Recipes written before this field default to 25 %, which is what they all ran at.
    strain_cap_pct: float = 25.0
    # Sensor crop, [OffsetX, OffsetY, Width, Height], or None to keep the specimen preset's.
    # Here rather than in the preset because the crop a MATERIAL needs is not the crop a COLOUR
    # needs: the shipped 2348 px width lets the marker pair separate to 33 % strain before a
    # marker reaches the edge, and the rig's 30 mm travel backstop is 37.5 % on an 80 mm gauge.
    # On an elastomer the markers therefore leave the frame BEFORE anything stops the test.
    roi: list = None
    # Travel at which the pull ends ITSELF, in mm, or None to run until fracture / by hand.
    # This is a TEST SETTING, not a safety limit: it is a clean Stop at a chosen extension, and
    # it must sit below POLICY_MAX_TRAVEL_MM (30 mm), which is the hard Stop+EStop backstop and
    # is not a nice way to end a run. For a specimen that never fractures it is the only thing
    # that ends the test other than the operator watching for the right moment.
    stop_travel_mm: float = None
    # Blob roundness gate, or None to keep the specimen preset's. A LOOSENING lives here rather
    # than in camera_manager so it reverts by itself when the profile changes - the 0.50 -> 0.40
    # edit made for the PETG campaign has been sitting in the preset for days with a roadmap
    # item to undo it, which is exactly the failure mode this avoids.
    min_circularity: float = None
    # Threshold and exposure (microseconds), or None to keep whatever is live. They belong
    # beside min_circularity because they are the SAME decision: the roundness gate is what
    # keeps a bright grip from being read as a marker, so loosening it is only safe with optics
    # that keep the grips dark. Pinning one and leaving the other to drift is how S36 froze Px0
    # on a grip edge at 2118 px against a true ~1700.
    threshold: int = None
    exposure_us: int = None
    # "manual", or the EXACT advanced-test-mode dropdown label ("Cyclic", "Staircase",
    # "Relaxation", "Creep", "Staircase → FRACTURE", "Progressive cyclic → FRACTURE").
    # Storing the label verbatim keeps load/save a straight lookup with no translation table.
    mode: str = "manual"
    strain_rate: float = 0.0005           # used by the strain-rate fracture test (1/s)
    # Per-mode settings, keyed by that same label:
    #   {"Cyclic": {"low": 100.0, "high": 500.0, "cycles": 5, "speed": 0.1, "waveform": "Sine"}, ...}
    # A dict rather than flat fields so a new mode needs no schema change, and so EVERY mode's
    # params round-trip (not just the selected one) — switching mode after a load keeps sane values.
    mode_params: dict = field(default_factory=dict)
    auto_stop_fracture: bool = True       # auto-halt the pull on load collapse
    notes: str = ""

    def path(self, directory=RECIPES_DIR):
        return os.path.join(directory, _slug(self.name) + ".json")

    def save(self, directory=RECIPES_DIR):
        p = self.path(directory)
        os.makedirs(directory, exist_ok=True)
        with open(p, "w", encoding="utf-8") as f:
            json.dump(asdict(self), f, indent=2, ensure_ascii=False)
        return p

    @classmethod
    def from_dict(cls, d):
        known = {f.name for f in fields(cls)}
        return cls(**{k: v for k, v in d.items() if k in known})

    @classmethod
    def load(cls, path):
        with open(path, encoding="utf-8") as f:
            return cls.from_dict(json.load(f))


def _slug(name):
    return "".join(c if (c.isalnum() or c in "-_") else "_" for c in str(name).strip()) or "recipe"


def list_recipes(directory=RECIPES_DIR):
    """All recipes in the folder, sorted by name (empty list if the folder is missing)."""
    if not os.path.isdir(directory):
        return []
    out = []
    for fn in sorted(os.listdir(directory)):
        if fn.endswith(".json"):
            try:
                out.append(TestRecipe.load(os.path.join(directory, fn)))
            except Exception:
                continue
    return sorted(out, key=lambda r: r.name.lower())


def find(name, directory=RECIPES_DIR):
    """Find a recipe by exact name or slug (case-insensitive)."""
    s = _slug(name).lower()
    for r in list_recipes(directory):
        if r.name.lower() == str(name).lower() or _slug(r.name).lower() == s:
            return r
    return None


DEFAULT = "Default"

# Superseded 2026-08-12 by the single "Default" profile below. Kept only so ensure_default() can
# recognise and retire the files it wrote in earlier sessions.
_RETIRED_DEFAULTS = ("Default 100% infill", "Default 50% infill")

# Back-compat alias: main.py and older code referred to the 100 % starter by name.
DEFAULT_100 = DEFAULT
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

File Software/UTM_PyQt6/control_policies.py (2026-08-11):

"""Software closed-loop control policies for the UTM  (Phase-0 F2 engine + Phase-B modes).

The auto-preload loop already proved the rig can be closed-loop-controlled in software:
read a live signal at ~11 Hz, compute the error, nudge SetSpeed. This module generalises
that ONE pattern into reusable *policies* so every test mode shares it.

Design contract (keeps hardware I/O and safety in the app, logic here):
  • A policy is PURE LOGIC + its own state. `step(Signals) -> Command`.
  • `Signals`  = the live readings the app already has (time, load N, position mm, DIC strain).
  • `Command`  = desired crosshead SPEED (mm/s, magnitude) + DIRECTION + a `done` flag.
  • The APP applies the command: maps direction to the firmware (Down = tension on this rig),
    throttles SetSpeed, and enforces the universal SAFETY NET (overshoot cap, max-force / max-
    travel limits, timeout, EStop, stall) ON TOP of whatever a policy asks for.

Validate every policy in `control_sim.py` (replay a CSV, or a spring plant) BEFORE any rig run.
No PyQt / hardware / matplotlib imports here — just logic, so it is unit-testable and safe.
"""
import math
from dataclasses import dataclass, field
from typing import Optional, List, Tuple


# ----------------------------------------------------------------------------------------
@dataclass
class Signals:
    t: float                       # seconds (monotonic clock the app already keeps)
    load: float                    # N   — current force (anchor/tare per the app's convention)
    pos: float                     # mm  — crosshead position / travel from tare
    strain: Optional[float] = None # DIC gauge (Cauchy) strain, or None if DIC not tracking


@dataclass
class Command:
    speed: float                   # mm/s, magnitude (>= 0). The app clamps to MAX and throttles.
    direction: str = "tension"     # "tension" | "compression" | "hold"
    done: bool = False             # True -> the mode finished; the app stops & resets
    message: str = ""              # short status for the console/status bar


def _interp(knots: List[Tuple[float, float]], x: float) -> float:
    """Piecewise-linear interpolation over (x, y) knots (same helper the preload used)."""
    if x <= knots[0][0]:
        return knots[0][1]
    for (x0, y0), (x1, y1) in zip(knots, knots[1:]):
        if x <= x1:
            return y0 + (y1 - y0) * (x - x0) / (x1 - x0) if x1 > x0 else y1
    return knots[-1][1]


class ControlPolicy:
    """Base class. Subclasses implement step(); may override start_message()."""
    name = "policy"

    def step(self, s: Signals) -> Command:                       # pragma: no cover - interface
        raise NotImplementedError

    def start_message(self) -> str:
        return f"{self.name}: started"


# ========================================================================================
# Phase-0 F2 — the existing auto-preload, now a policy (must reproduce current behaviour)
# ========================================================================================
class ForceRampPolicy(ControlPolicy):
    """Ramp in tension to a target force with a load-fraction speed schedule, stopping at
    `factor`x target (the 1.03x offsets PLA stress relaxation). This IS the current
    `_preload_check` / `_preload_speed` behaviour, extracted verbatim."""
    name = "force-ramp (preload)"
    KNOTS = [(0.0, 0.20), (0.10, 0.20), (0.15, 0.10), (0.50, 0.10), (0.90, 0.02), (1.0, 0.02)]

    def __init__(self, target_load: float, factor: float = 1.03, direction: str = "tension"):
        self.target = float(target_load)
        self.factor = factor
        self.direction = direction

    def step(self, s: Signals) -> Command:
        if self.target <= 0:
            return Command(0, "hold", done=True, message="invalid target")
        if s.load >= self.factor * self.target:
            return Command(0, "hold", done=True,
                           message=f"reached {s.load:.1f} N (target {self.target:.0f} N x{self.factor:.2f})")
        spd = _interp(self.KNOTS, s.load / self.target)
        return Command(spd, self.direction)

    def start_message(self) -> str:
        return f"Force-ramp to {self.target:.0f} N (stop at {self.factor:.2f}x)"


# ========================================================================================
# Phase-B — closed-loop test modes (all reuse the same step() contract)
# ========================================================================================
class StrainRatePolicy(ControlPolicy):
    """TRUE material strain-rate control: adjust crosshead speed so the DIC gauge strain rate
    d(ε)/dt tracks `target_rate` (1/s) — compliance-free, unlike constant crosshead speed.
    Feed-forward start + proportional correction from the measured rate; falls back to a
    nominal speed while DIC is unavailable. Stops at `stop_strain` or on load collapse."""
    name = "strain-rate"

    def __init__(self, target_rate: float, gauge_mm: float, stop_strain: Optional[float] = None,
                 nominal_gauge_share: float = 0.5, kp: float = 0.6,
                 speed_limits: Tuple[float, float] = (0.005, 1.8), collapse_frac: float = 0.5):
        self.target_rate = float(target_rate)
        self.gauge = float(gauge_mm)
        self.stop_strain = stop_strain
        self.kp = kp
        self.smin, self.smax = speed_limits
        self.collapse_frac = collapse_frac
        # feed-forward: crosshead speed ~ target_rate * L0 / (fraction of travel reaching the gauge)
        self._speed = min(self.smax, max(self.smin,
                          target_rate * gauge_mm / max(0.1, nominal_gauge_share)))
        self._hist: List[Tuple[float, float]] = []   # (t, strain) window for rate estimate
        self._peak = 0.0
        self._armed = False

    def step(self, s: Signals) -> Command:
        self._peak = max(self._peak, s.load)
        if self._peak > 0 and s.load >= 0.3 * self._peak:
            self._armed = True
        if self._armed and s.load < self.collapse_frac * self._peak:
            return Command(0, "hold", done=True, message="load collapse (fracture)")
        if s.strain is not None:
            if self.stop_strain is not None and s.strain >= self.stop_strain:
                return Command(0, "hold", done=True, message=f"reached ε {s.strain:.4f}")
            self._hist.append((s.t, s.strain))
            self._hist = [(t, e) for (t, e) in self._hist if t >= s.t - 0.6]   # ~0.6 s window
            if len(self._hist) >= 2 and self._hist[-1][0] > self._hist[0][0]:
                measured = (self._hist[-1][1] - self._hist[0][1]) / (self._hist[-1][0] - self._hist[0][0])
                err = self.target_rate - measured
                self._speed = min(self.smax, max(self.smin, self._speed + self.kp * err * self.gauge))
        return Command(self._speed, "tension")

    def start_message(self) -> str:
        return f"Strain-rate control @ {self.target_rate:.2e} /s (feed-fwd {self._speed:.3f} mm/s)"
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

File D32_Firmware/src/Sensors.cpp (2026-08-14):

#include "Sensors.h"

Sensors::Sensors(void) {
  Wire.begin();
}

// Select the input of the I2C Multiplexer
void Sensors::tcaselect(uint8_t i) {
  if (i > 1) {
    Serial.print("Error: We only have 2 sensors, index ");
    Serial.print(i);
    Serial.println(" provided.");
    return;
  }

  Wire.beginTransmission(TCAADDR);
  Wire.write(1 << i);
  Wire.endTransmission();
}

void Sensors::init(int id) {
  Serial.print("Selecting id");
  Serial.println(id);
  tcaselect(id);
  Serial.print("Initializing AS5600 id:");
  Serial.println(id);

  // If magnet is not detected
  if (as5600.detectMagnet() == 0) {
    while(1) {
      if (as5600.detectMagnet() == 1){
        Serial.print("Current Magnitude: ");
        Serial.println(as5600.readMagnitude());
        break;
      }
      else {
        Serial.println("Can not detect magnet");
        delay(1000);
      }
    }
  }
}

float Sensors::readAngle(int id) {
  // degrees per second
  tcaselect(id);
  return as5600.readAngle() * AS5600_RAW_TO_DEGREES;
}

void Sensors::posAndSpeed(int id){
  tcaselect(id);
  as5600.readAngle();
  Serial.print(as5600.getCumulativePosition(false));
  Serial.print("\t");
  Serial.println(as5600.getAngularSpeed(AS5600_MODE_DEGREES, false));
}

int32_t Sensors::readTotalPosition(int id){
  tcaselect(id);
  as5600.readAngle();

  return as5600.getCumulativePosition(false);

}

float Sensors::readAngularSpeed(int id){
  tcaselect(id);
  as5600.readAngle();

  return as5600.getAngularSpeed(AS5600_MODE_DEGREES, false);

}

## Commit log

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2026-01-02 Add serial communication and custom toggle switch widget
    - Add SerialManager class with QtSerialPort for firmware communication
    - Implement connection handshake with firmware version verification
    - Add safety measures: EStop and Disable on connect, Stop on disconnect
    - Create custom toggle switch widget in widgets.py (pure PyQt6)
    - Replace connection and motors checkboxes with toggle switches
    - Add motor safety: Stop command sent before Disable
    - Update UI file to use standard Qt widgets only
    [serial_manager.py, widgets.py]
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2026-01-03 Implement SpeedGauge widget with symmetric range and speed controls
    Add circular speed gauge widget with:
    - Symmetric range (-max to +max) with 0 at 12 o'clock
    - Needle indicator, color gradient (green→yellow→red)
    - Tick marks and labels for -max, 0, +max
    - Digital readout in center
    - Support for both RPM and mm/s units
    Speed control improvements:
    - MAX_RPM=450 safety limit in software
    - Speed spinbox uses editingFinished signal (updates on Enter only)
    - Movement start grace period for stall detection
    - Position/Velocity console display toggles
    [widgets.py]
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2026-01-03 v0.2.7: Non-blocking serial connection and UI improvements
    - Fix UI freeze when connecting to wrong COM port by using background
    worker thread with pyserial for port testing
    - Fix emergency stop not triggering full motor cleanup
    - Add scroll bars for smaller screens (QScrollArea wrapper)
    - Make Data Streams horizontal to reduce window height
    - Remove tick labels from speed gauge
    - Add pyserial dependency for non-blocking port probing
    [serial_manager.py, widgets.py]
2026-01-03 v0.3.0: Load plot with matplotlib, calibration, and bug fixes
    Features:
    - Embedded matplotlib canvas in Load Plot tab with real-time Force vs Time
    - RangeSlider custom widget for data cropping (two-handle, 0-100%)
    - Visual crop markers on plot (red dashed lines + yellow span)
    - Two-point load cell calibration workflow with progress dialog
    - Load Data panel shows current load, max load, and point count
    - Configurable display rate (default 0.01s = 100 Hz refresh)
    - Downsampling for performance (500 display points when > 1000 total)
    - Show/hide markers and auto-scale toggles
    Bug fixes:
    - Data collection only starts when BOTH loadCellSwitch AND plot checkbox enabled
    - X-axis datetime scaling no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
    [widgets.py]
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2026-07-10 F1: shared analysis library (utm_analysis.py); repoint v6_compare
    - New Software/UTM_PyQt6/utm_analysis.py = single source of truth:
    read_csv / linfit / find_fracture / analyze + LiveFractureDetector.
    Folds the load-collapse detector AND the V5-S4 strain-jump guard into
    one analyze() (used offline now, live in the app later).
    - v6_compare.py imports it and drops its ~60-line local copy; console
    output byte-identical (UTS 46.21, sy 44.98, E 2.60,
    ef 0.0298/0.0517/0.0732/0.0500/0.0744, k 1.26/1.11).
    - Same function now handles the brittle V5-S4 case correctly
    (ef 0.0247, not the 0.186 post-fracture DIC glitch).
    [utm_analysis.py]
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2026-07-15 One-click per-specimen PDF report generator (utm_report.py)
    - New Software/UTM_PyQt6/utm_report.py: build_report(csv, settings) -> a dense
    one-page landscape report (KPI strip, test settings, 4 plots, validation vs
    Chacon + add:north) as a VECTOR PDF (editable) + PNG, plus each graph saved
    individually as PDF+PNG. CLI + importable engine; uses the shared analysis
    library and matplotlib's OO API (safe to call inside the Qt app). Marks the
    preload level on the load-time & stress plots. Default output folder:
    Software/UTM_PyQt6/reports.
    - utm_analysis.py: expose c1 / sy_ec for the report's elastic + 0.2%-offset
    lines and sigma_y marker; docstring corrected to "engineering stress".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
    [utm_analysis.py, utm_report.py]
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2026-07-25 Phase C: shared live-DIC helpers (utm_dic.py) — health + Poisson/Cauchy math
    - dic_health(): summarise recent dic_history -> status/tracking%/jitter/drift for a live
    badge (OK/WARN/BAD + colour); health_text() one-liner.
    - Multi-marker geometry: classify_markers (top/bottom axial + left/right transverse),
    lateral_strain, poisson_ratio, current_area = A0(1+eps_lat)^2, cauchy_stress, and a
    poisson_cauchy() convenience. Pure functions; the 2-marker case returns transverse=None
    so axial-only behaviour is unchanged.
    - Self-tests pass: health OK/BAD/NO-DATA + missing-marker; geometry recovers nu=0.35,
    area < A0, Cauchy > engineering. No app/camera change here.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
    [utm_dic.py]
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2026-07-28 Infill as a recorded label (metadata only): parse in read_meta, show in report
    - utm_analysis.read_meta parses '# Specimen - ... Infill: N %' from the CSV header
    into meta['infill'] — a recorded label used in NO calculation.
    - utm_report shows an 'Infill (label)' row in TEST SETTINGS (dash when absent);
    row spacing tightened for the extra line.
    The app side (unversioned main.py) adds the 'Infill %' input with a tooltip stating
    it is label-only, and writes the value into saved settings + the CSV header. Stress is
    still F / nominal area regardless of infill.
    [utm_analysis.py, utm_report.py]
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2026-07-28 S16: first post-stall-guard fracture — auto-stop + stall-guard VALIDATED
    S16 (100% infill) fractured at UTS 47.4 MPa (3792 N true, anchor 418) - V6-consistent.
    - Auto-stop caught the load collapse (2992 -> -417 N); motor stopped at fracture.
    - Stall guard correctly stayed silent through the ductile draw (force falling while
    crosshead advanced) - near-zero-only threshold confirmed.
    - Fracture-test button worked end-to-end.
    Registry: added S16 (utm_registry._record now falls back to the CSV Infill header when
    the filename lacks the label). E 1.88 GPa is low vs V6 ~2.6 (early-elastic DIC noise?).
    [utm_registry.py]
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2026-07-29 Strain-rate: lower default rate 0.001 -> 0.0005 /s (recipe dataclass default)
    Part of the S17 6.2 fixes (rest in unversioned main.py): strain-rate crosshead cap
    dropped 0.4 -> 0.12 mm/s and default rate halved, so the stepper stays in its
    high-force band. At 0.4 mm/s a 100% specimen stalled at 2.9 kN that a steady
    0.10 mm/s pull took to 3.2+ kN (torque-speed, not thermal). Button also renamed
    "Start strain-rate fracture test"; stall guard added to the strain-rate loop.
    [utm_recipes.py]
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2026-08-08 Cyclic: add Triangle/Sine waveform selector
    CyclicPolicy gains waveform='triangle'|'sine'; sine eases speed by load
    fraction (spd=speed*sin(pi*frac)) so it crawls at each bound -> smooth
    rounded cycles, still exactly within Low/High. Sim-checked both (3 cycles,
    6 reversals; sine eases 0.036->0.5 mid-stroke). Cyclic help diagram now
    overlays both waveforms. UI selector wiring is in the unversioned main.py.
    [control_policies.py]
2026-08-08 Staircase: add Linear/Smooth ramp-shape selector
    StaircasePolicy gains ramp_shape='linear'|'smooth'; smooth eases speed by
    load fraction toward each level (spd=speed*sin(pi*frac)) -> gentler arrival,
    less overshoot. Sim-checked: smooth lands exactly on 200/400/600 N vs
    linear's 202/405/608. Staircase help diagram overlays both ramps. UI
    selector wiring is in the unversioned main.py.
    [control_policies.py]
2026-08-08 Creep: ease the approach to kill target overshoot
    Rig run T1 asked for 400 N and peaked at 448 N (+12%) before nudging back --
    the crosshead needs ~1 s to decelerate, so a full-speed arrival coasts past
    the target. CreepPolicy now tapers speed over the last 25% of the approach
    (ease_frac). Sim with a T1-calibrated plant (750 N/mm, 1 s decel): overshoot
    38.8 N -> 0.6 N, ramp ~3 s slower. Other policies unchanged (FSM regression OK).
    [control_policies.py]
2026-08-08 Staircase smooth ramp: taper only the top 25% (match CreepPolicy)
    Rig runs T3/T4 (same specimen, same settings) showed smooth cut overshoot
    45/47/53 N -> 6/5/8 N at the 300/600/900 N levels, but doubled ramp time
    because sin(pi*frac) also eased the START of each ramp, which buys no
    accuracy. Now full speed until within ease_frac of the level, then taper.
    Sim on a T3/T4-calibrated plant (850 N/mm, 1.24 s decel): overshoot stays
    <=1 N while ramp time drops 27.0s -> 18.0s (linear 11.2s). FSM regression OK.
    [control_policies.py]
2026-08-09 Cyclic: true-sine velocity law + adaptive predictive reversal
    Rig run T6 showed a stepped, non-sinusoidal wave and big bound violations
    (+71/-74 N triangle, +8/-23 N sine). Three causes, all addressed:
    1. sin(pi*frac) is not a sine in time. For F = mid-amp*cos(wt) the velocity
    must go as 2*sqrt(frac*(1-frac)); the old law was ~2x too slow near the
    bounds, flattening the shoulders and straightening the flanks.
    2. No reversal lead. Added a predictive reversal that triggers early by
    rate*decel, where decel is ADAPTED per direction from the bound violation
    actually observed (overshoot = rate*(true_decel-lead) => true_decel =
    lead + overshoot/rate). Damped update (gain 0.7) and se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
    [control_policies.py]
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2026-08-09 Cyclic: force-domain reversal lead + waveform shaped over achieved travel
    T6.2 (rig) exposed two structural faults in the previous version:
    1. FLAT BOTTOMS. The sine law clamped frac to the nominal bounds, so below
    f_low it returned 0 and the speed floor took over. Every reversal
    undershoots past f_low, so every cycle fell into that dead zone: measured
    0.0159 mm/s below the bound vs 0.0635 above, and climb-out of 10.4/10.6 s
    for troughs that dipped below vs 5.8/6.4 s for troughs that did not.
    Fix: shape the waveform over the ACHIEVED extremes (_lo_seen/_hi_seen),
    widened by shape_margin, and raise the floor 0.01 -> 0.02 mm/s.
    2. HIGH BOUND WOULD NOT CONVERGE (+7.9 -> +15.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
    [control_policies.py]
2026-08-09 Add two fracture protocols: staircase-to-fracture + progressive cyclic
    Both reach the same fracture as the monotonic pull but interrogate the
    specimen on the way, so ONE specimen yields a curve instead of a point.
    StaircaseToFracturePolicy (B): keeps adding steps until load collapse.
    Gives modulus re-measured per level, a mini stress-relaxation per level,
    and a sharp yield onset (dwell drop flat while elastic, grows past yield).
    Uses the shared LiveFractureDetector - correct here because the load never
    intentionally falls.
    ProgressiveCyclicPolicy (A): load-unload-reload with a RISING peak until
    fracture. Each unload gives the unloading modulus at that damage state ->
    stiffness degradation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
    [control_policies.py]
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2026-08-09 Raise the smooth-ramp taper floor 0.01 -> 0.02 mm/s
    At 0.01 mm/s the crosshead covers only 0.06 mm in the stall guard's 6 s
    window against its 0.05 mm bar -- a 1.2x margin, so a healthy motor can trip
    on rounding alone. 0.02 mm/s gives 0.12 mm = 2.4x. Applies to StaircasePolicy
    and StaircaseToFracturePolicy via a new min_ramp_speed attribute.
    Surfaced by rig run T7, which halted on the stall guard at 1888 N while the
    taper was commanding ~0.016 mm/s.
    [control_policies.py]
2026-08-09 Add find_dwells/yield_onset to the shared analysis library
    find_dwells detects staircase HOLDs on the COMMANDED speed (spd == 0), not a
    position-gradient threshold. A tapered approach crawls at 0.02 mm/s, which a
    gradient cut-off cannot separate from a real hold: on rig run T7.2 the
    |d(pos)/dt| < 0.004 rule silently missed 3 of 8 levels -- and those were the
    levels carrying the yield signal. The gradient rule is kept only as a fallback
    for older CSVs with no Speed_mm_s column (read_csv now exposes it as 'spd',
    NaN when absent).
    yield_onset returns the level where drop_pct stops falling and starts climbing
    = the yield knee. T7.2: min 1.60% at 694 N tared, rising to 3.23% by 1165 N.
    Lives in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
    [utm_analysis.py]
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2026-08-09 Recipes: store the advanced test mode + every mode's parameters
    A recipe could set dimensions/preload/speed/DIC but not which of the six
    advanced modes to run, nor its settings, so repeating a cyclic/staircase/creep
    test still meant retyping every field.
    TestRecipe gains:
    mode "manual", or the EXACT dropdown label. Stored verbatim so
    load/save is a straight lookup with no translation table to
    drift out of sync.
    mode_params dict keyed by that same label. A dict rather than flat fields
    so a new mode needs no schema change, and so EVERY mode's
    params round-trip, not just the selected one, which keeps sane
    v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
    [utm_recipes.py]
2026-08-09 Track the 7 remaining app source modules; correct requirements.txt
    These were never committed, so the app was not fully version-controlled:
    camera_manager.py, serial_manager.py, camera_setup.py, roi_tool.py,
    widgets.py, build_exe.py, requirements.txt. Checked before adding: no
    absolute/user paths, no credentials, largest is widgets.py at 24 KB, and
    none are matched by .gitignore.
    requirements.txt was inaccurate and the app could not be installed from it:
    ADDED opencv-python - cv2 is imported by camera_manager, camera_setup,
    roi_tool and main; it was missing entirely.
    ADDED pypylon - the Basler SDK, imported by camera_manager and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
    [camera_manager.py, camera_setup.py, serial_manager.py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]
2026-08-09 Track ui/utm_mainwindow.ui (app could not start without it) + dev scripts/docs
    CRITICAL: main.py line 48 does uic.loadUi("ui/utm_mainwindow.ui") and
    build_exe.py bundles it with --add-data, so the 53 KB Qt Designer file is a
    hard runtime dependency -- and it was untracked. A fresh clone could not have
    started the app. The previous commit's "fully version-controlled" check only
    walked .py modules and missed it; that claim was wrong until now.
    Also tracked: the camera/DIC diagnostic scripts (test_camera*.py, test_blob,
    test_threshold, check_blobs, annotate_utm), the phase-8.6 validation suite
    (test_phase_8_6.py, validate_phase_8_6.py, analyze_hardware_tests.py) and two
    docs (COMMANDS.txt chea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
    [check_blobs.py]
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2026-08-09 Two starter recipes replace the ad-hoc list; add help diagrams for both fracture modes
    RECIPES. The Settings dropdown had accumulated four entries (Default, T7, T8,
    Test 0) -- run-specific leftovers a student would have to guess between. It now
    offers exactly two, one per specimen type:
    Default 100% infill <- top of the list and the profile the app opens on
    Default 50% infill
    Both carry parameters for ALL SIX test types, not just the selected one, so
    switching the Test type after a Load gives sane values instead of leftovers
    from whatever was loaded before. Force parameters are sized from the validated
    runs so a fracture protocol reaches failure in ~10 levels/cycles: the 50%
    profile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
    [utm_recipes.py]
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2026-08-10 SF9: hysteresis/modulus/stress-strain/literature slides; fix a fabricated creep number
    Deck 60 -> 64 slides (pages 141-204). Four new: p200 stress-strain for all six
    modes, p201 cyclic hysteresis, p202 staircase modulus per level, p203 PLA vs
    literature. Register moves to p204 and its Slides column now points at them.
    THREE DATA ERRORS FOUND AND FIXED
    1. Creep was reported as "+3257 ue". A DIC dropout writes ec=0.0/lpx=0 into the
    row instead of skipping it, and the first row of the hold landed on one, so
    differencing manufactured the entire number. True drift is +0.00 ue/s against
    a +-12 ue noise band -- no resolvable creep at all. That is the physically
    correct answer: 4.98 MPa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
    [utm_report.py]
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2026-08-12 Report: title the strain-vs-crosshead graph for what it shows - the compliance gap
    'Gauge strain vs crosshead' named the axes; 'DIC strain vs crosshead - the compliance gap' names
    the point. The dotted reference is 'if every millimetre of crosshead became gauge strain', so the
    area between it and the measured curve IS the machine compliance - the same effect that makes the
    crosshead read stiffer while the specimen softens.
    Comment added at the call site recording why it is NOT 'strain rate': neither axis is time, so
    there is no de/dt anywhere on this plot.
    Verified by regenerating the full report from T7.3's CSV.
    [utm_report.py]
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2026-08-12 Px0: name the pixel reference for what it is, and let it be frozen BEFORE preload
    The operator's point is correct and it is a measurement issue, not a naming one. Strain is
    (Px - Px0)/Px0, so whatever is already stretched into the specimen when the reference is frozen is
    excluded from every reading for the rest of the test. The checklist told the operator to preload
    FIRST and then press Prepare, which tares DIC - so on a 300 N preload, 80 mm2, ~1.5 GPa specimen
    roughly 2500 ue was being silently discarded. That is 96x the 26 ue noise floor, and it is the same
    effect that makes T9's creep/instantaneous ratio an upper bound rather than a value.
    - 'Tare DIC' -> 'Calibrate Px0', and the 'L0:'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
    [theme.py]
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2026-08-13 Live feed: keep the frozen Px0 pair on screen beside the moving one
    Strain is (Px - Px0)/Px0, so Px0 is half the measurement -- but until now it
    existed only as a number in a label. Nothing on the feed said where the markers
    were when it was frozen, which meant a bad tare (slack specimen, tare taken
    under preload, a marker that jumped to a neighbouring blob) looked exactly like
    a good one until the strain came out wrong.
    camera_manager.tare_dic now keeps the two centroids as well as their separation,
    sorted along the loading axis so the frozen and live pairs zip marker-for-marker.
    Only the separation still enters the maths.
    The overlay tells the pairs apart by three things at once -- hue,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
    [camera_manager.py]
2026-08-13 Stop the GUI thread doing ~700 ms of work per second
    Profiled the two hot paths at the rig's real geometry rather than guessing. One
    matplotlib redraw of these figures costs 22.5 ms (14.2 ms of that is the
    datetime x-axis alone); one camera frame costs 5.9 ms on the GUI thread. At
    ~11 Hz load-cell data across two canvases plus 35 fps of feed, that is roughly
    700 ms of every wall-clock second spent on a single thread -- which is the lag.
    Four changes, none of which touch a measurement:
    Hidden tabs no longer redraw. Only one plot tab is ever on screen, but both
    canvases redrew on every tick, so half the plotting the app did was invisible by
    construction. The dirty flag deliberately stays set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
    [camera_manager.py]
2026-08-13 Dark blue Px0 reference; make radio/checkbox indicators visible in dark mode
    Three fixes from looking at the live feed on a real specimen.
    Frozen reference is now dark blue #0D47A1 instead of cyan. The screenshot
    showed something a synthetic frame could not: the frozen ring is drawn at a
    radius that straddles the EDGE of the speckle blob, so one stroke crosses
    near-black and near-white within a few pixels. No flat colour survives that, so
    every frozen mark is now laid down twice -- a white casing, then the colour --
    which is what makes a dark colour usable there at all.
    The colour change is also the right call on the numbers, not just taste.
    Measured as OKLab dE x100 against the live green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
    [theme.py]
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2026-08-13 DIC frame capture: PNG stills and AVI recording, off the hot path
    Settings menu gets two independent features -- "Save DIC frames as PNG" and
    "Record DIC video as AVI" -- each with Start/Stop beside it. Both OFF by
    default, and ticking one only ARMS it: capture actually begins when a test
    starts (advanced mode or Fracture test) or when Start now is pressed. Two small
    chips sit beside the DIC health badge, REC blinking at 2 Hz like a camera, CAP
    steady -- a blinking pair reads as an error rather than as two states.
    The constraint was that none of this may slow the feed, the plots or the data
    rate, so the design came from measurement rather than guesswork:
    cv2 RELEASES the GIL while encoding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
    [camera_manager.py, utm_capture.py]
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2026-08-13 Record raw and speckle simultaneously; fix a boolean that never restored false
    MULTIPLE VIDEO VIEWS. CaptureManager holds a LIST of video sinks instead of one,
    so any combination of Raw / Speckle / Boosted records at the same time into one
    run folder -- video.avi beside video_speckle.avi. Raw and speckle answer
    different questions (archival record vs marker motion at a glance), so wanting
    both is the normal case. Each view gets its own worker and file; the camera
    thread still hands the frame over once.
    The style menu splits accordingly: video views are multi-select, PNG stills stay
    SINGLE. Stills are the expensive sink at ~1.9 GB/min and a second copy of every
    frame would double that for a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
    [utm_capture.py]
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2026-08-14 SF12: DIC auto-calibration, and show the camera settings in the GUI
    The preset's exposure and threshold were chosen once, by hand, under one set of
    LEDs. When the lighting drifts those numbers quietly stop being right and the
    first symptom is a ruined test.
    utm_autocal.py turns "does it look OK" into a number. Pure NumPy/OpenCV on a
    supplied frame -- no camera, no Qt, no app state -- so the scoring is testable
    against synthetic and recorded frames. Exactly two blobs is a hard GATE, not a
    deduction: one marker means no gauge length and three means the detector found
    something that is not a marker. Past that, CONTRAST MARGIN dominates the score,
    because it predicts whether tracking survives a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
    [camera_manager.py, utm_autocal.py]
2026-08-14 Manual camera parameters, alongside auto-calibrate, with a live trackability check
    Settings > DIC camera setup now offers both routes: "Auto-calibrate..." (the
    sweep) and "Set parameters manually..." -- a dialog for exposure, threshold,
    Otsu on/off, the blob area gates and circularity.
    The dialog's point is the LIVE READOUT, not the fields. Every change re-scores
    the current frame through utm_autocal and reports it in words: "2 markers .
    score 0.92 -- good", or "1 marker(s) found -- need exactly 2. Nothing is
    measured until this reads 2." Typing numbers blind is exactly how the preset's
    exposure and threshold came to be wrong under the current lighting -- they were
    right once, and nothing s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
    [utm_camdlg.py]
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2026-08-14 Fix the fracture-index bug that made epsilon_f a function of DIC row density
    ROOT CAUSE. A CSV row only carries a DIC reading when one landed within
    DIC_STALE_THRESHOLD_MS of that load sample; every other row is written with
    ec = 0.0 and lpx = 0.0. The strain-jump guard in find_fracture required
    data[i-1] and data[i] to BOTH be tracked -- ADJACENT rows -- which silently made
    it a function of how densely DIC happened to fall in the file:
    V5 2026-06-12 3057/3057 rows tracked -> 100.0 % adjacent pairs
    V6b 2026-06-25 1555/2658 -> 52.4 %
    S24 2026-08-14 571/2135 -> 7.3 % <- guard DEAD
    On S24 a dropout row sat exactly between the last intact s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
    [utm_analysis.py, utm_registry.py]
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
